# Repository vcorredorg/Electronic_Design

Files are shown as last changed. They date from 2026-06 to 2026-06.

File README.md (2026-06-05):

# Lock-in Amplifier
## Overview

This repository contains the development files, documentation, firmware, and interface resources for a digital lock-in amplifier based on the open-source OLIA architecture. The project implements a compact embedded instrumentation system capable of extracting amplitude, phase, and harmonic information from weak periodic signals using synchronous detection techniques.

A lock-in amplifier is especially useful when the signal of interest is buried in noise or when conventional amplitude measurements are not sufficient. By using a known reference signal, the system can isolate the component of the measured signal that is correlated with the reference frequency. This makes the instrument suitable for experimental electronics, sensors, optical measurements, signal characterization, and academic instrumentation projects.

The implementation is built around the Teensy 4.0 microcontroller and developed using Visual Studio Code, PlatformIO, and Zephyr. In addition to the embedded firmware, the project includes a basic graphical user interface for visualizing magnitude, phase, and harmonic components, as well as modifying user-configurable acquisition and processing parameters.

## Project Purpose

The main purpose of this project is to develop a low-cost, configurable, and educational digital lock-in amplifier that can be used as an alternative to conventional laboratory instrumentation in controlled experimental environments.

Many measurement systems require detecting very small periodic signals in the presence of broadband noise, DC offsets, interference, or unwanted spectral components. Direct measurement methods may fail when the signal-to-noise ratio is too low. This project addresses that problem by implementing digital synchronous demodulation, allowing the system to recover the amplitude and phase of a signal at a known reference frequency and at selected harmonic components.

The project also aims to document the complete engineering development process, including firmware structure, signal-processing logic, hardware documents, user-interface design, requirements, testing procedures, and system validation. Therefore, the repository is intended not only as a functional implementation but also as a technical reference for understanding how a microcontroller-based lock-in amplifier can be designed, programmed, tested, and documented.

## Main Features

* Embedded signal-processing system using the Teensy 4.0 development board.
* Synchronous detection for extracting signal magnitude and phase relative to a reference signal.
* Harmonic analysis for evaluating signal components at selected multiples of the reference frequency.
* Firmware developed with PlatformIO and Zephyr inside Visual Studio Code.
* Modular firmware organization for acquisition, processing, configuration, communication, and reporting tasks.
* Basic graphical user interface for:

  * Magnitude visualization.
  * Phase visualization.
  * Harmonic visualization.
  * User-defined configuration parameters.
* Project documentation organized for academic and engineering use.
* Adaptable architecture for future improvements such as calibration, advanced filtering, data logging, communication protocols, and extended visualization tools.

## Repository Structure

The repository is organized to separate hardware design files, technical documentation, embedded firmware, and the graphical user interface. The structure follows the general organization of the OLIA reference project, which separates firmware, GUI, board files, and documentation, while adapting it to this Teensy 4.0 + Zephyr + PlatformIO implementation.

```text
.
├── README.md
│
├── altium/
│   ├── files/
│   └── gerbers.zip
│
├── documents/
│   ├── application_note.pdf
│   └── power_tree/
|   └── block diagram
|   └──slides
|   └──technical_data.csv
│
├── firmware/
│       ├── CMakeLists.txt
│       └── src/
│           ├── main.c
│           ├── app/
│           │   ├── control.c
│           │   ├── control.h
│           │   ├── serial_protocol.c
│           │   └── serial_protocol.h
│           ├── dsp/
│           │   ├── lockin_core.c
│           │   └── lockin_core.h
│           └── hal/
│               ├── adc_backend.c
│               ├── adc_backend.h
│               ├── gpio_backend.c
│               ├── gpio_backend.h
│               ├── pwm_backend.c
│               ├── pwm_backend.h
│               ├── uart_backend.c
│               └── uart_backend.h
│
└── gui/
    ├── lockin_gui.py
    └── requirements.txt
```

Suggested directory purpose:

* `firmware/`: contains the embedded code for the Teensy 4.0, including acquisition, demodulation, harmonic calculation, configuration handling, and communication modules.
* `hardware/`: contains connection diagrams, schematics, wiring references, datasheets, and hardware-related notes.
* `documents/`: contains the formal project documentation, including requirements, architecture, state diagram and design explanations.
## Technologies Used

* **Teensy 4.0**
  Main embedded processing platform. The Teensy 4.0 is based on an ARM Cortex-M7 microcontroller running at 600 MHz, which provides enough computational capability for real-time digital signal processing, harmonic calculation, communication handling, and user-configuration tasks. Its floating-point support and high clock frequency make it suitable for implementing a compact digital lock-in amplifier.

* **PlatformIO**
  Embedded development environment used to manage project configuration, dependencies, compilation, board settings, and firmware upload.

* **Zephyr**
  Real-time operating system used to structure the embedded application into manageable tasks, improve modularity, and support a more organized firmware architecture.

* **Visual Studio Code**
  Main development environment used for firmware editing, project management, compilation, and debugging workflow.

* **C / C++**
  Primary programming language for the embedded firmware, signal-processing routines, hardware abstraction, and communication logic.

* **Graphical User Interface**
  Basic interface developed to display magnitude, phase, and harmonic information, and to allow user configuration of the system.

## Reference Project

This project is based on the open-source OLIA project:

* OLIA Repository: https://github.com/ajharvie/OLIA

OLIA is an open digital lock-in amplifier designed around the Teensy 4.0. This repository uses OLIA as a technical reference and adapts its concepts to the specific goals, implementation decisions, and documentation structure of this project.

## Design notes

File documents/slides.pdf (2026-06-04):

# PROYECTO - DISEÑO

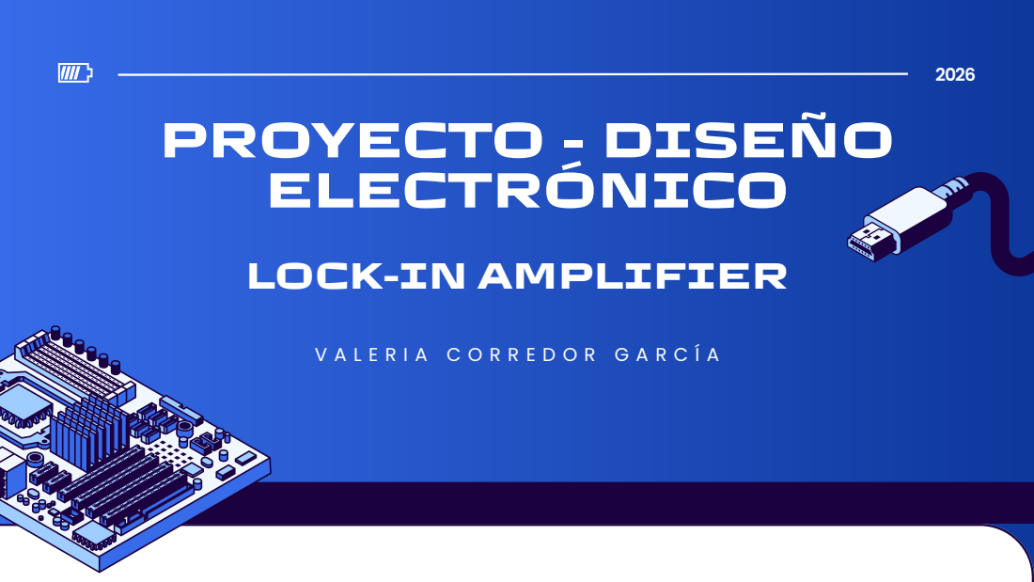
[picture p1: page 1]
ELECTRÓNICO

LOCK-IN AMPLIFIER

P

R

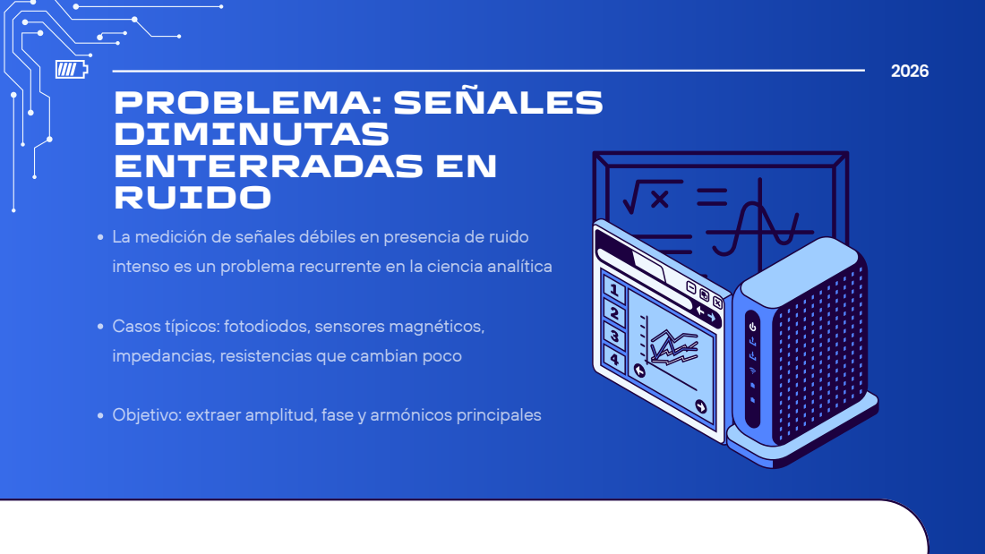
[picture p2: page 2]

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
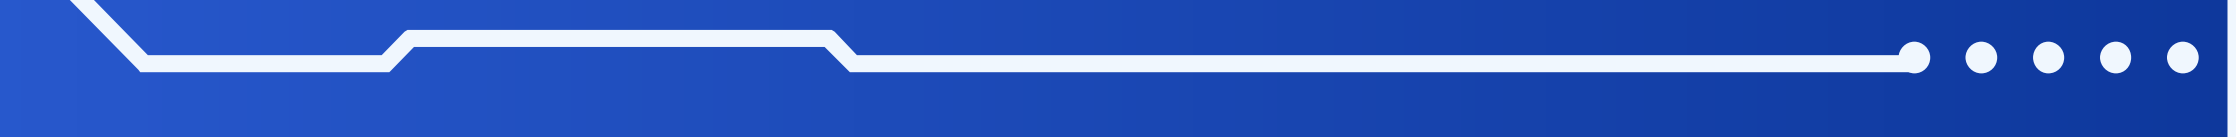
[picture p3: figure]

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
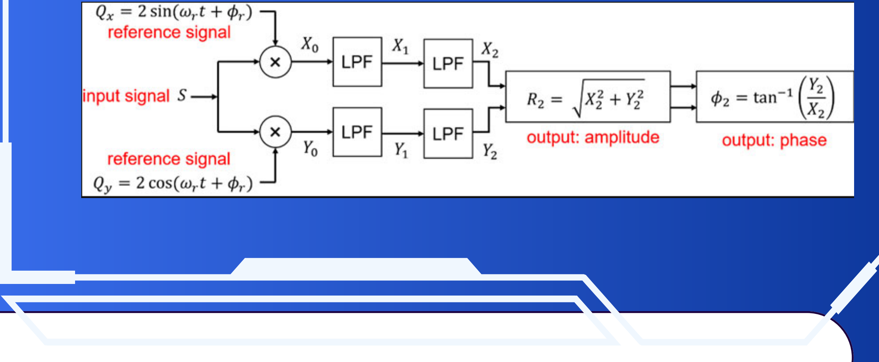
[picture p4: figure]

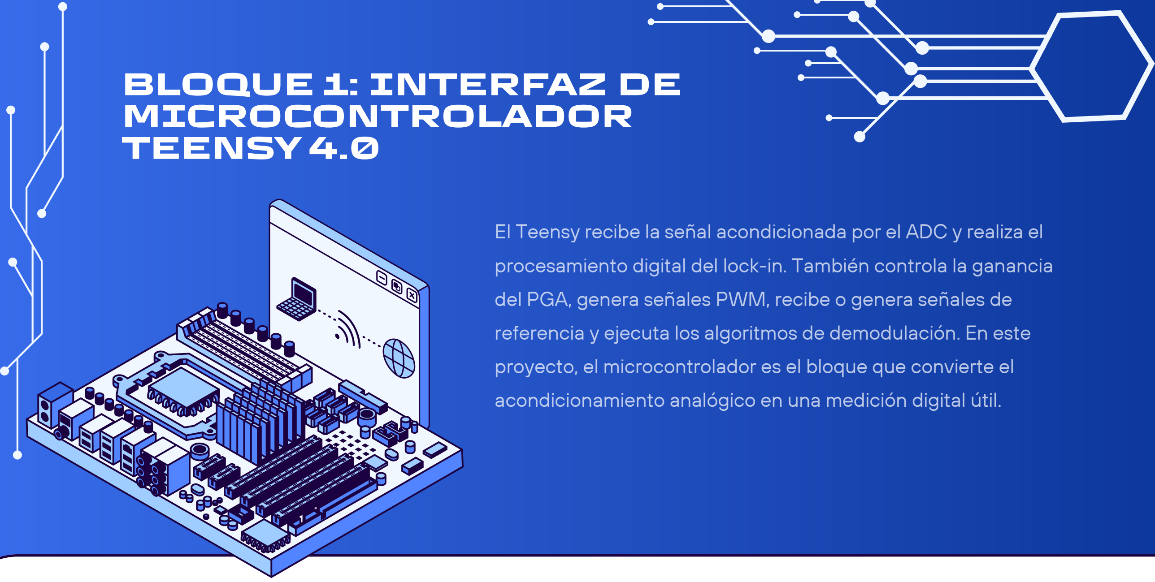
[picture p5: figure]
BLOQUE 1: INTERFAZ DE MICROCONTROLADOR TEENSY 4.0

El Teensy recibe la señal acondicionada por el ADC y realiza el procesamiento digital del lock-in. También controla la ganancia del PGA, genera señales PWM, recibe o genera señales de referencia y ejecuta los algoritmos de demodulación. En este proyecto, el microcontrolador es el bloque que convierte el acondicionamiento analógico en una medición digital útil.

## BLOQUE 2: RIEL DE VOLTAJE NEGATIVO

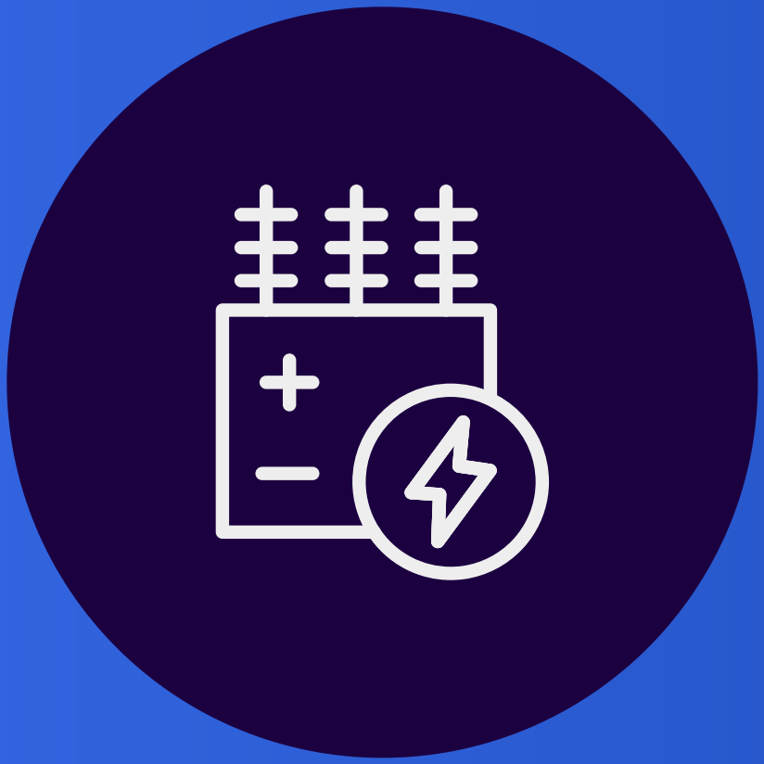
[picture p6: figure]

Este bloque crea un riel de tensión negativa a partir de la alimentación positiva disponible. La tensión negativa permite que los amplificadores analógicos trabajen con señales bipolares. Esto es importante porque la señal de entrada del lock-in puede estar centrada alrededor de cero y no solo en valores positivos.

B

L

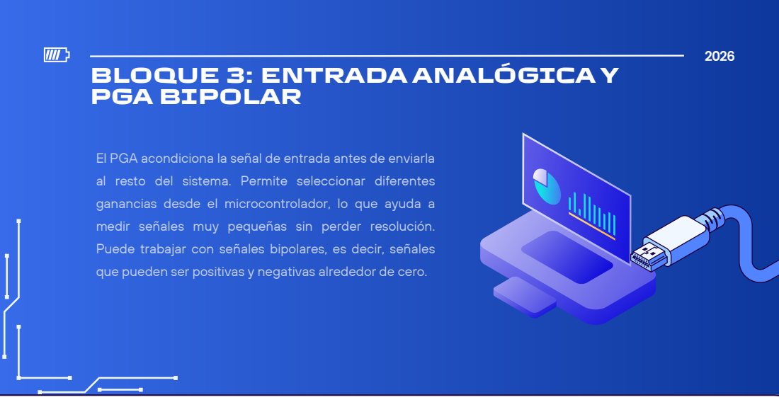
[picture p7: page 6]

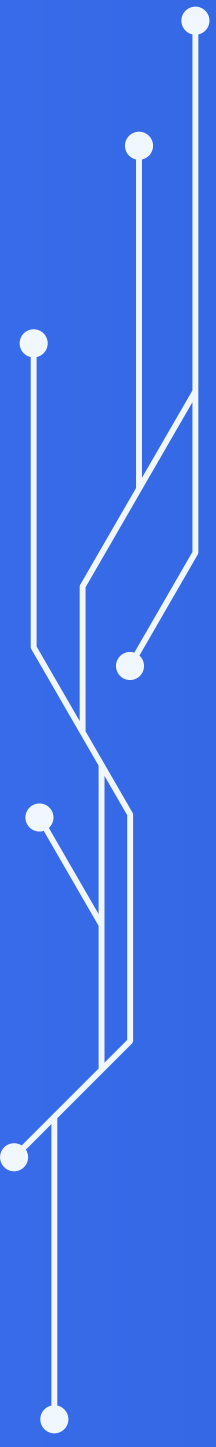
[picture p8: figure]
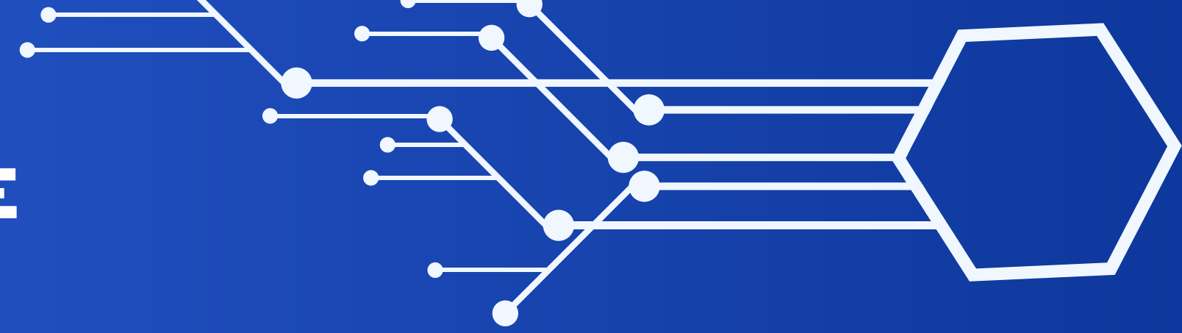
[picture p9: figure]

## BLOQUE 4: ETAPA DE OFFSET

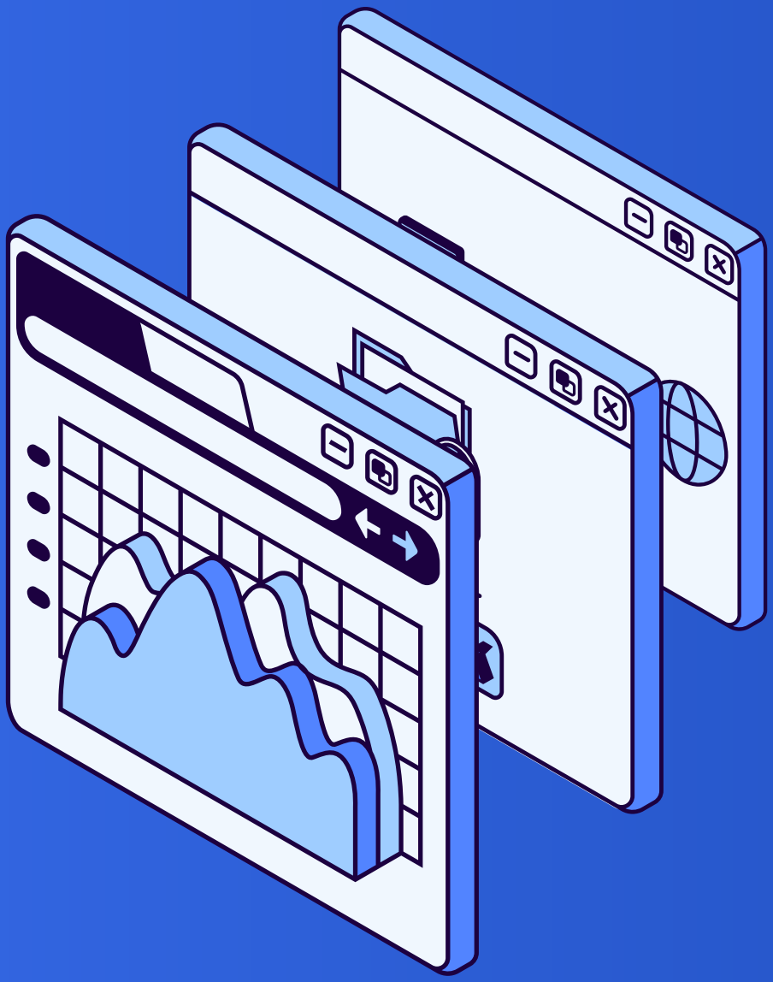
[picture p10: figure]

Después de acondicionar la señal se adaptarla a la entrada del ADC. Como el ADC del microcontrolador solo trabaja con tensiones positivas, este bloque desplaza la señal hacia un rango seguro de lectura. En otras palabras, convierte una señal centrada en cero en una señal centrada alrededor de un nivel positivo, sin perder la información de variación de la señal original.

## BLOQUE 5: FILTRO ANTI ALIAS

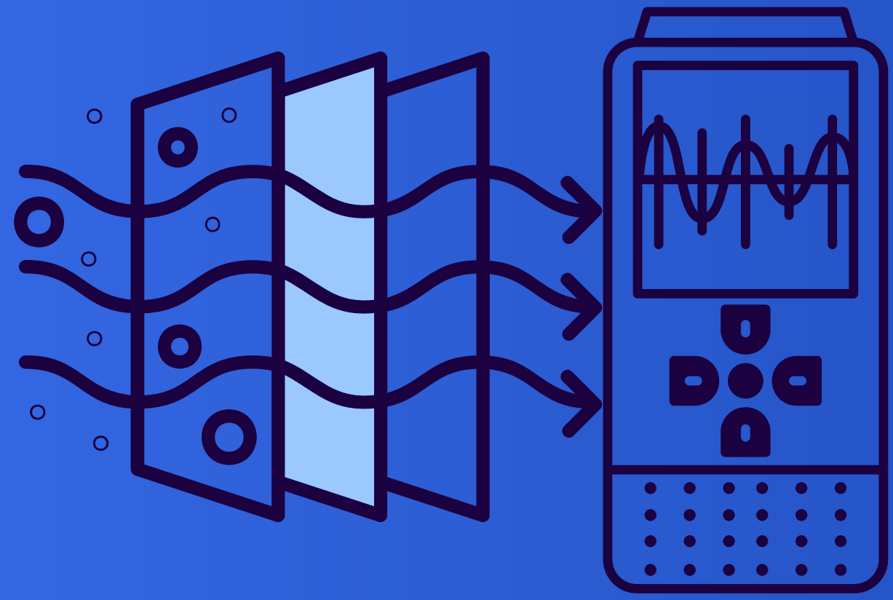
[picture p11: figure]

El filtro anti-aliasing elimina componentes de alta frecuencia que podrían producir errores durante el muestreo. Su objetivo es que el ADC reciba una señal más limpia y que las frecuencias no deseadas no se mezclen con la señal útil. Esto es importante en un lock-in amplifier porque la medición depende de extraer una componente muy específica de frecuencia.

## BLOQUE 6: SALIDA ANALÓGICA PWM FILTRADA

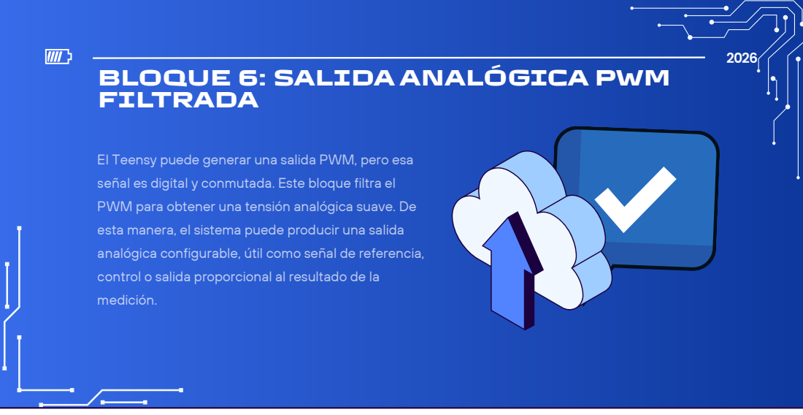
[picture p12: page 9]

El Teensy puede generar una salida PWM, pero esa
señal es digital y conmutada. Este bloque filtra el
PWM para obtener una tensión analógica suave. De
esta manera, el sistema puede producir una salida
analógica configurable, útil como señal de referencia,
control o salida proporcional al resultado de la
medición.

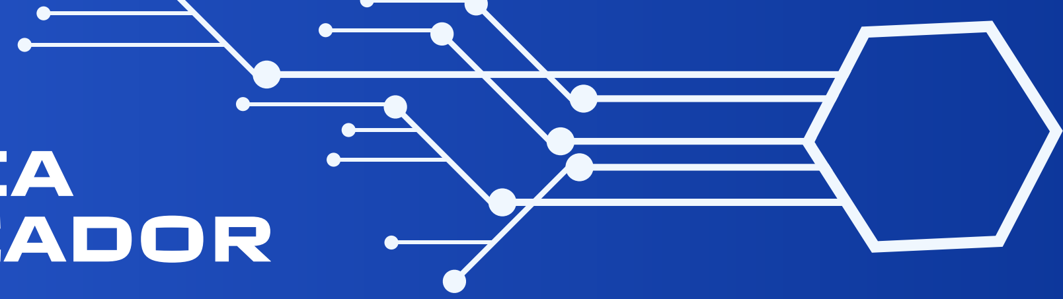
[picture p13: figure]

## BLOQUE 7: REFERENCIA EXTERNA Y MULTIPLICADOR DE RELOJ X64

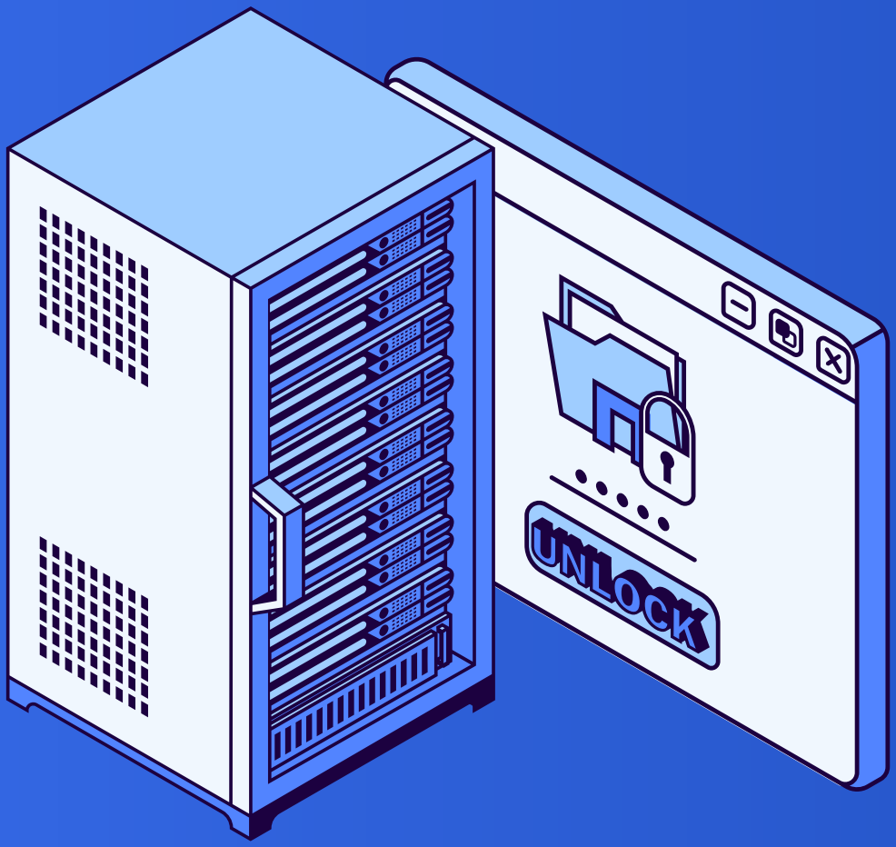
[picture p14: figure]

Este bloque toma una referencia externa y usa un PLL para generar un reloj sincronizado de mayor frecuencia. La multiplicación por 64 permite obtener una referencia temporal más fina para el procesamiento digital. En un lock-in amplifier, la sincronización con la referencia es esencial, porque la señal medida se compara con esa referencia para extraer amplitud y fase..

# MUCHAS

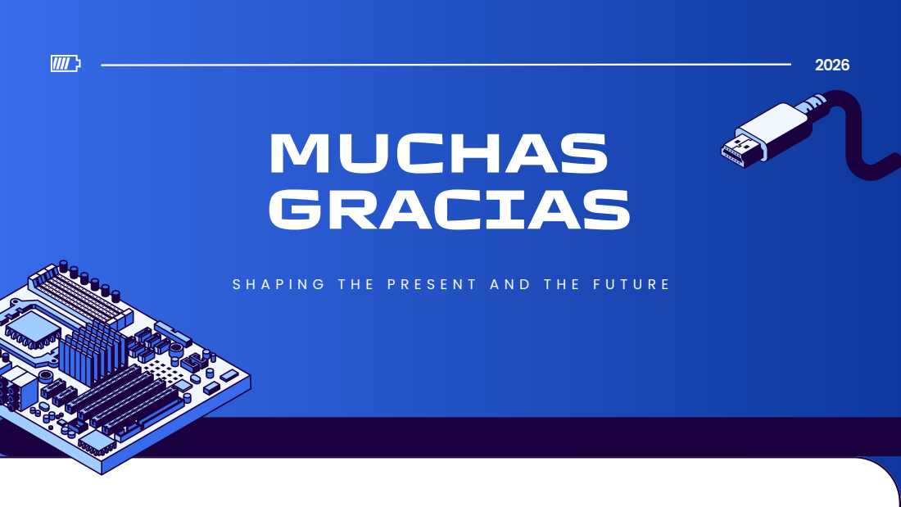
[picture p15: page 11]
GRACIAS

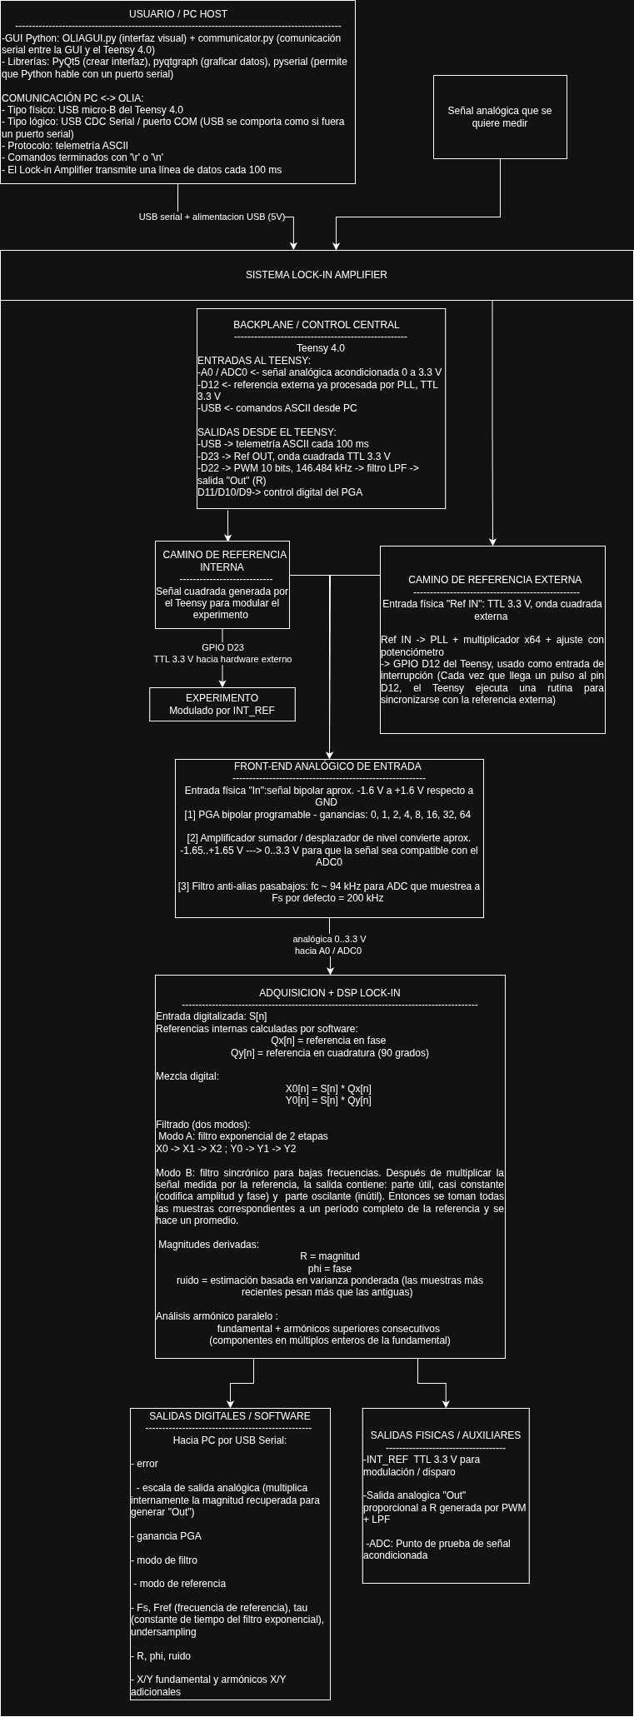
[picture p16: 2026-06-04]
documents/block diagram.png

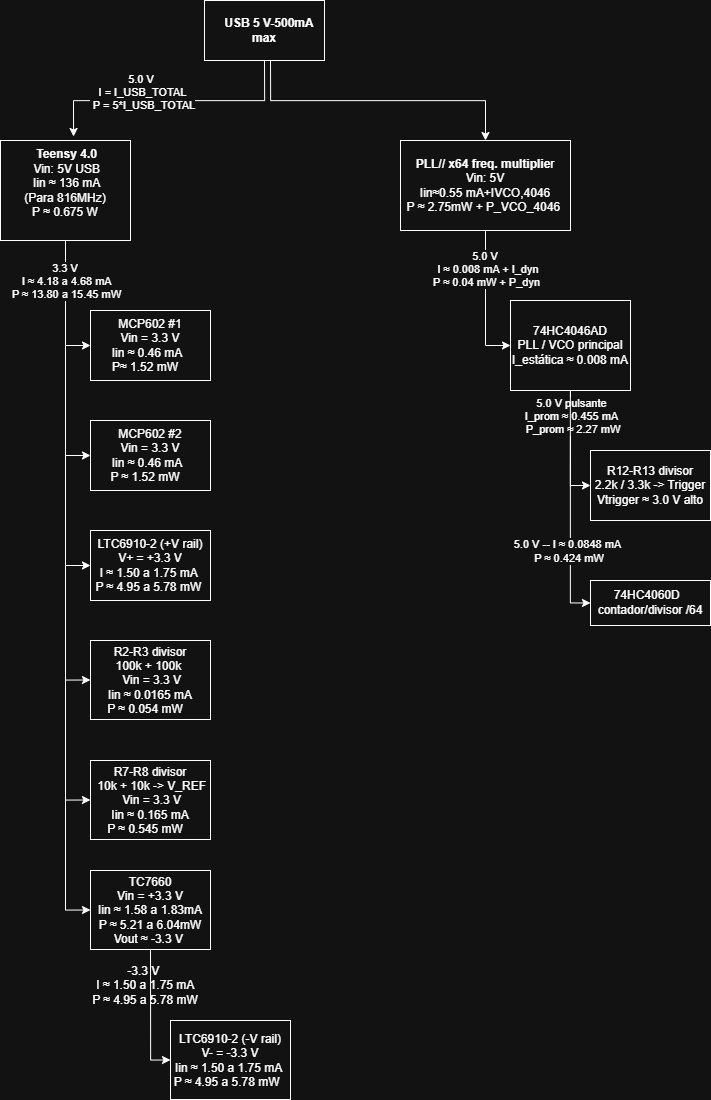
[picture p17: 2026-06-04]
documents/power_tree/power_tree.png

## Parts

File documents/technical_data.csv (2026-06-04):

Tabla 1 — Frecuencias, tasas y tiempos importantes
Parámetro | Valor | Parte del sistema | Importancia para el proyecto | Fuente / referencia
Frecuencia de CPU de Teensy 4.0 | 600 MHz | Microcontrolador Teensy 4.0 | Frecuencia principal de procesamiento; permite adquisición, demodulación digital, cálculo de magnitud/fase y armónicos en tiempo real. | https://www.pjrc.com/store/teensy40.html
Cristal principal de Teensy 4.0 | 24 MHz | Reloj base del microcontrolador | Referencia física usada por la Teensy para generar el reloj del sistema mediante PLL interno. | https://www.pjrc.com/store/teensy40.html
SysTick | 1 kHz equivalente | Temporización del sistema | Genera una base temporal de 1 ms para tareas periódicas no críticas, monitoreo o temporización general. | https://www.pjrc.com/store/teensy40.html
Velocidad USB device | 480 Mbit/s | Comunicación Teensy-PC | Enlace principal para enviar datos procesados a la interfaz gráfica. | https://www.pjrc.com/store/teensy40.html
Rango de frecuencia lock-in Amplifier | 10 Hz – 50 kHz | Referencia del proyecto base | Rango funcional declarado para lock-in amplifier digital; sirve como referencia de desempeño. | https://github.com/OpenLockIn/OLIA
Frecuencia de modulación interna | 1 Hz – 50 kHz | Modo de referencia interna | La GUI permite modificar la frecuencia de modulación interna dentro de este rango. | https://doi.org/10.3389/fsens.2023.1102176
Tasa de digitalización por defecto | 200 kHz | ADC / adquisición | Define el límite de Nyquist, la carga computacional y el número de armónicos que pueden calcularse. | https://doi.org/10.3389/fsens.2023.1102176
Periodo de muestreo asociado | 5 µs | ADC / DSP | Corresponde a Ts = 1 / 200000; es la ventana temporal disponible por muestra. | https://doi.org/10.3389/fsens.2023.1102176
Frecuencia de Nyquist del ADC | 100 kHz | Adquisición digital | Mitad de 200 kHz; señales por encima pueden producir aliasing si no se filtran antes del ADC. | Cálculo directo a partir de Fs = 200 kHz
Filtro anti-aliasing analógico | 94 kHz | Acondicionamiento analógico | Filtro pasa-bajas previo al ADC, ubicado por debajo de Nyquist para atenuar componentes superiores. | https://doi.org/10.3389/fsens.2023.1102176
Multiplicador de referencia externa | ×64 | PLL externo / hardware de referencia | Genera 64 ciclos de reloj por cada ciclo TTL de referencia externa. | https://doi.org/10.3389/fsens.2023.1102176 ; https://raw.githubusercontent.com/vcorredorg/Electronic_Design/main/documents/power_tree/power_tree.png
Divisor de referencia | /64 | 74HC4060D / referencia | Bloque usado para dividir la señal generada o reconstruir relaciones de referencia. | https://raw.githubusercontent.com/vcorredorg/Electronic_Design/main/documents/power_tree/power_tree.png
Rango de referencia externa del PLL OLIA | 130 Hz – 6 kHz | Modo de referencia externa | Rango de entrada TTL externa para los valores de diseño indicados. | https://doi.org/10.3389/fsens.2023.1102176
Límite de cambio de estrategia de muestreo externa | 1562.5 Hz | Referencia externa | Por debajo de este valor se toman muestras en flanco de subida y bajada, logrando 128 muestras por ciclo TTL. | https://doi.org/10.3389/fsens.2023.1102176
Segundo umbral de referencia externa | 3125 Hz | Referencia externa | Entre 1562.5 Hz y 3125 Hz se toman 64 muestras por ciclo TTL; por encima se submuestrea. | https://doi.org/10.3389/fsens.2023.1102176
Muestras por ciclo en referencia externa baja | 128 muestras/ciclo | ADC sincronizado | Aplica para f_TTL < 1562.5 Hz; mejora la resolución de fase por ciclo. | https://doi.org/10.3389/fsens.2023.1102176
Muestras por ciclo en referencia externa media | 64 muestras/ciclo | ADC sincronizado | Aplica entre 1562.5 Hz y 3125 Hz. | https://doi.org/10.3389/fsens.2023.1102176
Muestras por ciclo en referencia externa alta | 64/N muestras/ciclo | ADC sincronizado | Para f_TTL > 3125 Hz, con N = 2, 4, 8, 16, para mantener Fs bajo 200 kHz. | https://doi.org/10.3389/fsens.2023.1102176
Actualización de datos por USB/GUI | 0.1 s = 10 Hz | Interfaz gráfica | Frecuencia de envío/actualización de valores de magnitud, fase, componentes X/Y y ruido hacia la GUI. | https://doi.org/10.3389/fsens.2023.1102176
Constante de tiempo configurable | 0.01 s – 10 s | Filtro digital | Controla el compromiso entre rechazo de ruido y velocidad de respuesta. | https://doi.org/10.3389/fsens.2023.1102176
Tiempo de estabilización recomendado | ≈ 10τ | Medición lock-in | Después de cambiar una configuración, se recomienda esperar aproximadamente diez constantes de tiempo. | https://doi.org/10.3389/fsens.2023.1102176
Límite típico para filtrado síncrono | < 100 Hz | DSP / filtrado | Recomendado principalmente para señales limpias de baja frecuencia. | https://doi.org/10.3389/fsens.2023.1102176
PWM en Teensy 4.0 | 31 pines PWM, 19 grupos de frecuencia | Salidas digitales | Puede servir para generar señales de referencia, modulación o control; la frecuencia depende de configuración por software. | https://www.pjrc.com/store/teensy40.html
Tabla 2 — Datos técnicos importantes del proyecto
Dato | Valor / descripción | Uso en la exposición | Fuente / referencia
Entrada analógica OLIA | −1.6 V a +1.6 V aprox. | Rango bipolar de entrada del proyecto de referencia. | https://github.com/OpenLockIn/OLIA
Rango de entrada acondicionado al ADC | 0 V – 3.3 V | La señal bipolar se desplaza/acondiciona para ser compatible con el ADC de la Teensy. | https://doi.org/10.3389/fsens.2023.1102176
Resolución ADC usada en OLIA | 12 bits | Las muestras del ADC se obtienen como enteros de 12 bits y luego se procesan digitalmente. | https://doi.org/10.3389/fsens.2023.1102176
Precisión de cálculo | 64-bit double | Los cálculos digitales usan doble precisión aprovechando la FPU de la Teensy 4.0. | https://doi.org/10.3389/fsens.2023.1102176
Ganancia de entrada OLIA | 0, 1, 2, 4, 8, 16, 32, 64 | Permite adaptar señales pequeñas o grandes al rango útil del ADC. | https://doi.org/10.3389/fsens.2023.1102176
Armónicos por defecto en OLIA | Fundamental + armónicos 2, 3 y 4 | A 200 kHz hay margen computacional para analizar tres armónicos adicionales además de la fundamental. | https://doi.org/10.3389/fsens.2023.1102176
Armónicos si se reduce muestreo | Hasta 7 armónicos superiores a 100 kHz | Al bajar la frecuencia de muestreo aumenta el tiempo disponible por muestra, permitiendo calcular más armónicos. | https://doi.org/10.3389/fsens.2023.1102176
Alimentación principal en el power tree | USB 5 V, 500 mA máx. | Fuente general del sistema según el diagrama de potencia del repositorio. | https://raw.githubusercontent.com/vcorredorg/Electronic_Design/main/documents/power_tree/power_tree.png
Consumo estimado Teensy en el power tree | ≈ 136 mA, ≈ 0.675 W | Dato útil para justificar el presupuesto de potencia de la placa. | https://raw.githubusercontent.com/vcorredorg/Electronic_Design/main/documents/power_tree/power_tree.png
Interfaz de usuario | GUI para visualización y configuración | Permite observar magnitud, fase, armónicos y modificar parámetros de usuario. | https://github.com/vcorredorg/Electronic_Design/tree/main

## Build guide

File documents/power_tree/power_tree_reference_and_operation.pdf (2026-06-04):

REFERENCIAS DEL POWER TREE

- Teensy 4.0(MCU): https://www.pjrc.com/store/teensy40.html
A 600MHz consume 100mA, para 816MHz (aproximación), muestras de 12 bits

Iin =

816MHz ∗ 100mA
600MHz = 136mA
- TC7660 (genera riel de -3.3 V para operación bipolar del PGA):
-Datasheet: https://ww1.microchip.com/downloads/en/DeviceDoc/21465C.pdf -Conmuta a 10kHz, bajo consumo de corriente, requiere solo dos capacitores externos;

Pout ≈ 3.3 ⋅ (1.50 a 1.75) mA ≈ 4.95 a 5.78 mW

El datasheet del TC7660 dice que tiene una eficiencia de potencia típica de 98%, entonces:

Pin ≈

Pout
η

y como la entrada es de aproximadamente +3.3 V:

Iin ≈

Pout
η ⋅ Vin

Como en este caso Vin ≈∣ Vout ∣≈ 3.3 V, eso se simplifica mucho:

Iin ≈

Iout
η

Si se toma η ≈ 0.98, entonces:

Iin ≈

1.50 a 1.75
0.98 ≈ 1.53 a 1.79 mA

y después se suma el consumo propio del chip: Iin_total ≈ 1.53 a 1.79 + 0.08 ≈ 1.61 a 1.87 mA

- LTC6910-2(PGA-ajusta la ganancia de entrada):
-Datasheet: https://www.analog.com/media/en/technical-documentation/datasheets/6910fb.pdf (https://www.analog.com/media/en/technical-documentation/data-sheets/6910fb.pdf)
-Inversor, reduce componentes externos, ganancia-ancho de banda típico de aproximadamente 13 MHz en ganancia 64 bajo ciertas condiciones.

El datasheet menciona “: Vs = ±5V: 3mA o 3.5mA”, entonces para aproximar:

I+ ≈ I− ≈

Itotal
2
Por lo tanto:

I−3.3V ≈

3.0 mA
2

= 1.50 mA

I−3.3V ≈

3.5 mA
2

= 1.75 mA

Ganancia | Rango de entrada aproximado antes del ADC
0 | Entrada apagada
1 | ±1.65 V
2 | ±825 mV
4 | ±412 mV
8 | ±206 mV
16 | ±103 mV
32 | ±51.6 mV
64 | ±25.8 mV
- MCP602 (filtro):
- Datasheet:https://ww1.microchip.com/downloads/aemDocuments/documents/APID/ProductDocuments/DataSheets/20001685E.pdf
- Amplificador operacional CMOS doble (dos op-amps independientes), rail to rail.
- Se muestrea por defecto a 200 kS/s, por lo que la frecuencia de Nyquist es:
fN = 100 kHz

Por eso usa un filtro antialiasing de 94 kHz, ligeramente por debajo de Nyquist.
- El MCP602 tiene un producto ganancia-ancho de banda típico de 2.8 MHz y es estable en ganancia unitaria.
Iin (por amplificador):230uA; como es Dual
230uA ∗ 2 = 0.46mA por cℎip ETAPA DE OFFSET
- R2 y R7: divisor para crear 1.65 V: 10k e I= 165uA Es suficientemente baja para no gastar mucha potencia, pero suficientemente alta para que el nodo de 1.65 V no sea demasiado frágil.

- R3 y R5: promedian señal + offset: Como la entrada del op-amp idealmente no consume corriente, ese nodo queda aproximadamente como el promedio de ambas tensiones
- R4 y R6: amplificador no inversor con ganancia 2

ETAPA DE FILTRO ANTI-ALIASING: filtro pasa-bajas activo tipo Sallen-Key de ganancia unitaria, con frecuencia de corte en 94kHz

Fc =

1
2 ∗ π√R1 ∗ R2 ∗ C1 ∗ C2
-Filtro PWM:

Fc =

1
2 ∗ π ∗ R ∗ C

= 1. 6 Hz

La PWM de OLIA trabaja alrededor de 146 kHz, eso significa que la componente rápida de PWM queda fuertemente atenuada. El filtro deja pasar el valor promedio lento, pero elimina casi por completo el rizado rápido.

- 74HC4046AD (PLL-sincroniza fase y genera la frecuencia multiplicada): sistema de realimentación. Su objetivo no es simplemente generar una frecuencia, sino hacer que un oscilador local siga la fase de una señal de referencia.
- Datasheet:https://assets.nexperia.com/documents/data-sheet/74HC_HCT4046A.pdf Se divide la corriente en dos partes:

I4046 ≈ Iestaˊ tica + Idinaˊmica

Iestaˊ tica = 8uA
Cálculo de Iprom(corriente promedio del divisor resistivo que puse a la salida del VCO hacia el Teensy):
por las dos resistencias en serie es (una de 2.2 kΩ y una de 3.3 kΩ):

Ialto =

V
R12 + R13

=

5
2.2k + 3.3k

=

5
5.5k

= 0.909 mA

el divisor consume aproximadamente:
Ialto ≈ 0.909 mA
Pero el datasheet del 4046 dice que, cuando el nivel DC de VCO_IN se mantiene constante, la señal VCO_OUT tiene un duty cycle de 50 % con una desviación máxima esperada de 1 %. Eso quiere decir que, idealmente, la señal pasa la mitad del tiempo en alto y la mitad del tiempo en bajo. Cuando está en bajo, la corriente del divisor es prácticamente:

Ibajo ≈ 0

Entonces la corriente promedio del divisor es:

Iprom = D ⋅ Ialto

con D = 0.5. Por tanto:
Iprom = 0.5 ⋅ 0.909 mA = 0.4545 mA ≈ 0.455 mA
- la hoja de datos indica que el VCO necesita un capacitor externo entre C1A y C1B, y una resistencia externa hacia tierra para definir el rango de frecuencia

Determinar el rango de frecuencia del VCO
- C4= 820pF: C14 es el capacitor de temporización del VCO. Internamente, el 4046 carga y descarga ese capacitor. La frecuencia aumenta cuando el capacitor se carga y descarga más rápido. Al aumentar C14, baja la frecuencia máxima. Al reducir C14, sube la frecuencia máxima, pero el circuito se vuelve más sensible a capacitancias parásitas.
- P1=200K: Ajustar P1 cambia el rango de frecuencia libre del VCO. Esto es importante porque un PLL no puede bloquear cualquier frecuencia arbitraria: el VCO debe ser capaz de generar aproximadamente:

fVCO ≈ 64fEXTREF

Si el VCO libre está demasiado lejos, el lazo puede no capturar la referencia. P1 permite calibrar el rango. En un lock-in, esto es útil porque la referencia externa puede cambiar, y el reloj interno debe poder seguirla. -----------------------------------------------------------------------------------------------------------
- PC2OUT: Este es el comparador de fase 2, que en realidad es un detector de fase. PC2 no solo sabe si una señal está adelantada o atrasada; también sabe si una frecuencia es mayor o menor que la otra

Filtro R12-C16-R14: Este filtro convierte los pulsos de corrección del comparador de fase en una tensión relativamente suave para el VCO
- R12 = 220 kΩ limita la corriente de carga/descarga desde PC2OUT hacia el nodo PLLCTRL. Hace que el PLL no reaccione violentamente a cada pulso.
-C16 = 1.5 µF almacena la tensión de control. Es la “memoria analógica” del PLL. -.R14 = 4.7 kΩ introduce un cero en la respuesta del filtro. Esto ayuda a la estabilidad y evita que el lazo sea excesivamente integrador y oscilatorio.
- 74HC4060D (cuenta y divide la frecuencia): https://assets.nexperia.com/documents/data-sheet/74HC_HCT4060.pdf Retomando:

I4046 ≈ Iestaˊ tica + Idinaˊmica
De acuerdo con el datasheet:

Iestaˊ tica = 8uA

Se toma el peor caso del lock-in amplifier en referencia externa: el multiplicador genera 64 ciclos por cada ciclo de referencia y admite hasta 6 kHz (de ref externa).
f ≈ 64 × 6 kHz = 384 kHz
La parte dinámica se calcula con la fórmula que da el propio datasheet usando la capacitancia de disipación CPD:

PD = CPD VCC

2 fi N + ∑(CL VCC

2 fo)

y para el 74HC4060 a 5 V el datasheet da CPD = 40 pF con N = 1 (número de entradas del chip que están cambiando de estado - RS).
Entonces:

Pdinamica ≈ CPD V

2 f
Al sustituir:

Pdinamica ≈ 40 × 5

2 × 0.384

Pdinamica ≈ 40 × 25 × 0.384

Pdinamica ≈ 0.384 mW
Para la corriente dinámica:

Idinamica =

P
V

=

0.384 mW
5 V

= 0.0768 mA

Ahora se suma:
Itotal ≈ 0.008 + 0.0768 = 0.0848 mA

y luego la potencia total: P = V ⋅ I = 5 × 0.0848 mA = 0.424 mW

- Divisores resistivos: Las corrientes de esos bloques se calculan con:

I =

V

Rtotal

R11 = 2.2 kΩ y R13 = 3.3 kΩ: La salida VCLOCK del 4046 está alimentada a 5 V, así que su nivel alto será cercano a 5 V. Pero si TRIGGER va hacia una Teensy 4.0, no conviene aplicar 5 V directamente: PJRC indica que los pines digitales de Teensy 4.0 aceptan señales de 0 a 3.3 V y no son tolerantes a 5 V

El divisor hace:

VTRIGGER = VVCLOCK

R13
R11 + R13

Con tus valores:

VTRIGGER = 5V

3.3k
2.2k + 3.3k
VTRIGGER ≈ 3.0V

RESUMEN DE FUNCIONAMIENTO PLL:

1. Entra señal de referencia externa
2. Se compara señal externa con la PLLDIV64 por medio de PC2OUT (entrega pulsos de corrección)
3. Filtro de lazo: convierte los pulsos digitales de PC2OUT en una tensión analógica llamada PLLCTRL
4. Realimentación con PLLCTRL
5. Se genera VCOCLK
6. Luego VCLOCK se divide en el 4060
7. La señal PLLDIV64 vuelve al pin 3 del 4046

-La idea fundamental es esta:

f(t) =

1
2π

dφ(t)
dt

La frecuencia es la derivada temporal de la fase. Por eso, si dos señales tienen una diferencia de fase constante, entonces sus frecuencias son iguales. Un PLL usa este principio:
1. Compara la fase de una señal externa con la fase de una señal generada localmente.

Compara:

fEXTREF contra

fVCLOCK
64 = fPLLDIV64

Por eso, cuando el PLL está bloqueado:

fEXTREF =

fVCLOCK
64

y por tanto:

fVCLOCK = 64fEXTREF

fPLLDIV64 = fEXTRF y además intenta que queden con una diferencia de fase estable. Idealmente:

φPLLDIV64 ≈ φEXTRF

-Si PLLDIV64 va más lenta que la referencia, el PLL sube el voltaje PLLCTRL, aumentando la frecuencia del VCO. Si PLLDIV64 va más rápida, baja PLLCTRL, reduciendo la frecuencia del VCO. Cuando ambas tienen la misma frecuencia y una fase estable, se dice que el PLL está locked o enganchado.

2. el 4046 genera VCLOCK, el 4060 divide VCLOCK entre 64, y el 4046 ajusta su VCO hasta que la señal dividida coincida con la referencia externa.

-VCLOCK entra al 4060.

-El 4060 cuenta pulsos.

-Una salida intermedia se llama PLLDIV64.

-PLLDIV64 vuelve al pin COMPIN del 4046.

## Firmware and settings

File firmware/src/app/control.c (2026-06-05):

#include "zephyr_compat.h"
#include "control.h"
#include "serial_protocol.h"
#include "lockin_core.h"
#include "adc_backend.h"
#include "gpio_backend.h"
#include "pwm_backend.h"
#include "uart_backend.h"

#include <errno.h>
#include <stddef.h>
#include <stdint.h>
#include <string.h>

#define SAMPLE_STACK_SIZE   4096
#define REPORT_STACK_SIZE   4096
#define SERIAL_STACK_SIZE   2048
#define CONTROL_STACK_SIZE  2048

#define SAMPLE_PRIORITY     0
#define CONTROL_PRIORITY    2
#define SERIAL_PRIORITY     3
#define REPORT_PRIORITY     4

K_THREAD_STACK_DEFINE(sample_stack, SAMPLE_STACK_SIZE);
K_THREAD_STACK_DEFINE(report_stack, REPORT_STACK_SIZE);
K_THREAD_STACK_DEFINE(serial_stack, SERIAL_STACK_SIZE);
K_THREAD_STACK_DEFINE(control_stack, CONTROL_STACK_SIZE);

static struct k_thread sample_thread;
static struct k_thread report_thread;
static struct k_thread serial_thread;
static struct k_thread control_thread;

static struct k_sem sample_sem;
static struct k_sem report_sem;
static struct k_sem control_sem;

static struct k_timer sample_timer;
static struct k_timer report_timer;
static struct k_timer external_gate_timer;

static atomic_t external_measure_done;
static atomic_t external_measure_active;
static atomic_t started;

static void start_internal_sampling_from_config(void)
{
    lockin_config_t cfg;
    lockin_core_get_config(&cfg);
    uint32_t dt = cfg.sample_dt_us;
    if (dt < 1u) {
        dt = 1u;
    }
    k_timer_start(&sample_timer, K_USEC(dt), K_USEC(dt));
}

static void sample_timer_handler(struct k_timer *timer)
{
    ARG_UNUSED(timer);
    k_sem_give(&sample_sem);
}

static void report_timer_handler(struct k_timer *timer)
{
    ARG_UNUSED(timer);
    k_sem_give(&report_sem);
}

static void external_gate_timer_handler(struct k_timer *timer)
{
    ARG_UNUSED(timer);
    atomic_set(&external_measure_done, 1);
    atomic_set(&external_measure_active, 0);
    k_sem_give(&control_sem);
}

static void external_sample_callback(void)
{
    if (!atomic_get(&external_measure_active)) {
        k_sem_give(&sample_sem);
    }
}

static void sample_entry(void *a, void *b, void *c)
{
    ARG_UNUSED(a);
    ARG_UNUSED(b);
    ARG_UNUSED(c);

    while (1) {
        k_sem_take(&sample_sem, K_FOREVER);
        uint16_t sample = 0;
        if (adc_backend_read(&sample) == 0) {
            lockin_core_process_sample(sample, lockin_now_us32());

            gpio_backend_set_reference(lockin_core_reference_high());
        }
    }
}

static void report_entry(void *a, void *b, void *c)
{
    ARG_UNUSED(a);
    ARG_UNUSED(b);
    ARG_UNUSED(c);

    char line[384];
    while (1) {
        k_sem_take(&report_sem, K_FOREVER);
        lockin_snapshot_t snapshot;
        lockin_core_snapshot(&snapshot);
        int n = serial_protocol_format_report(&snapshot, line, sizeof(line));
        if (n > 0) {
            uart_backend_write(line, (size_t)n);
        }
        uint16_t code = lockin_core_pwm_code_from_snapshot(&snapshot, 1023u);
        pwm_backend_write_code(code, 1023u);
    }
}

static void serial_entry(void *a, void *b, void *c)
{
    ARG_UNUSED(a);
    ARG_UNUSED(b);
    ARG_UNUSED(c);

    char line[80];
    size_t pos = 0;

    while (1) {
        uint8_t ch = 0;
        if (uart_backend_get_char(&ch) != 0) {
            continue;
        }

        if (ch == '\r' || ch == '\n') {
            if (pos > 0u) {
                line[pos] = '\0';
                serial_protocol_handle_line(line);
                pos = 0u;
            }
            continue;
        }

        if (pos < (sizeof(line) - 1u)) {
            line[pos++] = (char)ch;
        } else {
            pos = 0u;
        }
    }
}

static void apply_external_measurement_result(void)
{
    uint32_t edges = gpio_backend_get_and_clear_edge_count();
    float trigger_hz = (float)edges / 10.0f;

    uint32_t undersampling = 1u;
    uint32_t oversampling = 1u;
    uint32_t samples_per_period = LOCKIN_REFERENCE_MULTIPLIER;
    bool both_edges = false;

    if (trigger_hz <= 100000.0f) {
        undersampling = 1u;
        oversampling = 2u;
        samples_per_period = LOCKIN_REFERENCE_MULTIPLIER * 2u;
        both_edges = true;
    } else if (trigger_hz <= 200000.0f) {
        undersampling = 1u;
        oversampling = 1u;
        samples_per_period = LOCKIN_REFERENCE_MULTIPLIER;
    } else if (trigger_hz <= 400000.0f) {
        undersampling = 2u;
        oversampling = 1u;
        samples_per_period = LOCKIN_REFERENCE_MULTIPLIER / 2u;
    } else if (trigger_hz <= 800000.0f) {
        undersampling = 4u;
        oversampling = 1u;
        samples_per_period = LOCKIN_REFERENCE_MULTIPLIER / 4u;
    } else {
        undersampling = 8u;
        oversampling = 1u;
        samples_per_period = LOCKIN_REFERENCE_MULTIPLIER / 8u;
    }

    lockin_core_set_external_timing(trigger_hz, undersampling, oversampling, samples_per_period);
    gpio_backend_enable_external_irq(both_edges);
}

static void control_entry(void *a, void *b, void *c)
{
    ARG_UNUSED(a);
    ARG_UNUSED(b);
    ARG_UNUSED(c);

    while (1) {
        k_sem_take(&control_sem, K_FOREVER);
        if (atomic_cas(&external_measure_done, 1, 0)) {
            apply_external_measurement_result();
        }
    }
}

int control_init(void)
{
    k_sem_init(&sample_sem, 0, 1);
    k_sem_init(&report_sem, 0, 1);
    k_sem_init(&control_sem, 0, 1);

    k_timer_init(&sample_timer, sample_timer_handler, NULL);
    k_timer_init(&report_timer, report_timer_handler, NULL);
    k_timer_init(&external_gate_timer, external_gate_timer_handler, NULL);

    lockin_core_init();

    int ret = adc_backend_init();
    if (ret != 0) {
        printk("adc init failed: %d\n", ret);
    }

    ret = gpio_backend_init();
    if (ret != 0) {
        printk("gpio init failed: %d\n", ret);
    }

    gpio_backend_set_external_sample_callback(external_sample_callback);
    gpio_backend_set_gain_bits(LOCKIN_DEFAULT_GAIN);

    ret = pwm_backend_init();
    if (ret != 0) {
        printk("pwm init failed: %d\n", ret);
    }

    ret = uart_backend_init();
    if (ret != 0) {
        printk("uart init failed: %d\n", ret);
    }

    return 0;
}
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

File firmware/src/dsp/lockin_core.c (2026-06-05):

#include "zephyr_compat.h"
#include "lockin_core.h"

#include <string.h>

/*
 * Zephyr 2.7.1 in PlatformIO/Teensy can fail during the pre-link stage when
 * libm is pulled in. Keep this firmware self-contained: no sinf/cosf/sqrtf/
 * atan2f/fabsf symbols are required from libm. Accuracy is sufficient for a
 * first hardware bring-up; later this can be replaced by a LUT or CMSIS-DSP.
 */
static float lk_absf(float x)
{
    return (x < 0.0f) ? -x : x;
}

static float lk_wrap_pi(float x)
{
    const float two_pi = 2.0f * LOCKIN_PI;
    while (x > LOCKIN_PI) {
        x -= two_pi;
    }
    while (x < -LOCKIN_PI) {
        x += two_pi;
    }
    return x;
}

static float lk_sinf(float x)
{
    x = lk_wrap_pi(x);
    float x2 = x * x;
    /* 7th-order odd polynomial around 0 after wrapping to [-pi, pi]. */
    return x * (1.0f - (x2 / 6.0f) + ((x2 * x2) / 120.0f) - ((x2 * x2 * x2) / 5040.0f));
}

static float lk_cosf(float x)
{
    return lk_sinf(x + (0.5f * LOCKIN_PI));
}

static float lk_sqrtf(float x)
{
    if (x <= 0.0f) {
        return 0.0f;
    }
    float g = (x >= 1.0f) ? x : 1.0f;
    for (int i = 0; i < 8; ++i) {
        g = 0.5f * (g + (x / g));
    }
    return g;
}

static float lk_atan2f(float y, float x)
{
    if (x == 0.0f) {
        if (y > 0.0f) { return 0.5f * LOCKIN_PI; }
        if (y < 0.0f) { return -0.5f * LOCKIN_PI; }
        return 0.0f;
    }

    float abs_y = lk_absf(y) + 1.0e-12f;
    float angle;

    if (x >= 0.0f) {
        float r = (x - abs_y) / (x + abs_y);
        angle = (0.25f * LOCKIN_PI) - (0.25f * LOCKIN_PI * r);
    } else {
        float r = (x + abs_y) / (abs_y - x);
        angle = (0.75f * LOCKIN_PI) - (0.25f * LOCKIN_PI * r);
    }

    return (y < 0.0f) ? -angle : angle;
}


static lockin_config_t cfg;

static float x_in_f1[LOCKIN_MAX_HARMONICS];
static float x_in_f2[LOCKIN_MAX_HARMONICS];
static float y_qu_f1[LOCKIN_MAX_HARMONICS];
static float y_qu_f2[LOCKIN_MAX_HARMONICS];
static float x_mean[LOCKIN_MAX_HARMONICS];
static float y_mean[LOCKIN_MAX_HARMONICS];
static float x_var[LOCKIN_MAX_HARMONICS];
static float y_var[LOCKIN_MAX_HARMONICS];
static uint16_t sync_buffer[LOCKIN_SYNC_BUFFER_LEN];

static uint32_t sample_index;
static uint32_t time_to_sample;
static uint32_t newest_index;
static uint32_t oldest_index;
static uint32_t last_sample_us;
static uint32_t last_loop_us;
static float clip_value;
static float unlock_value;
static float alpha;
static float alpha_min;

static void recalc_internal_timing(void)
{
    if (cfg.signal_hz < 0.1f) {
        cfg.signal_hz = 0.1f;
    }
    if (cfg.sample_hz < 1.0f) {
        cfg.sample_hz = 1.0f;
    }

    cfg.samples_per_period = (uint32_t)(cfg.sample_hz / cfg.signal_hz);
    if (cfg.samples_per_period < 1u) {
        cfg.samples_per_period = 1u;
    }

    cfg.sample_dt_us = (uint32_t)(1000000.0f / cfg.sample_hz);
    if (cfg.sample_dt_us < 1u) {
        cfg.sample_dt_us = 1u;
    }

    cfg.sample_hz_true = 1000000.0f / (float)cfg.sample_dt_us;
    cfg.signal_hz_true = cfg.sample_hz_true / (float)cfg.samples_per_period;

    alpha = 1.0f / (cfg.sample_hz_true * cfg.time_constant_s);
    if (alpha < 0.0000001f) {
        alpha = 0.0000001f;
    }
    if (alpha > 1.0f) {
        alpha = 1.0f;
    }
    alpha_min = 1.0f - alpha;
}

static void reset_filters_unlocked(void)
{
    memset(x_in_f1, 0, sizeof(x_in_f1));
    memset(x_in_f2, 0, sizeof(x_in_f2));
    memset(y_qu_f1, 0, sizeof(y_qu_f1));
    memset(y_qu_f2, 0, sizeof(y_qu_f2));
    memset(x_mean, 0, sizeof(x_mean));
    memset(y_mean, 0, sizeof(y_mean));
    memset(x_var, 0, sizeof(x_var));
    memset(y_var, 0, sizeof(y_var));
    sample_index = 0u;
    time_to_sample = 0u;
    newest_index = 0u;
    oldest_index = 1u;
    last_sample_us = 0u;
    last_loop_us = 0u;
    clip_value = 0.0f;
    unlock_value = 0.0f;
}

void lockin_core_init(void)
{
    cfg.signal_hz = LOCKIN_DEFAULT_SIGNAL_HZ;
    cfg.sample_hz = LOCKIN_DEFAULT_SAMPLE_HZ;
    cfg.time_constant_s = LOCKIN_DEFAULT_TAU_S;
    cfg.phase_offset_rad = 0.0f;
    cfg.output_scale = LOCKIN_DEFAULT_OUTPUT_SCALE;
    cfg.calibration_factor = LOCKIN_INPUT_CAL;
    cfg.gain = LOCKIN_DEFAULT_GAIN;
    cfg.first_harmonic = 2u;
    cfg.last_harmonic = cfg.first_harmonic + LOCKIN_HARMONIC_COUNT - 1u;
    cfg.undersampling = 1u;
    cfg.oversampling = 1u;
    cfg.sync_filter_enabled = false;
    cfg.external_reference_enabled = false;
    recalc_internal_timing();
    reset_filters_unlocked();
    memset(sync_buffer, 0, sizeof(sync_buffer));
}

void lockin_core_reset_state(void)
{
    unsigned int key = irq_lock();
    reset_filters_unlocked();
    irq_unlock(key);
}

void lockin_core_clear_sync_buffer(void)
{
    unsigned int key = irq_lock();
    memset(sync_buffer, 0, sizeof(sync_buffer));
    newest_index = 0u;
    oldest_index = 1u;
    irq_unlock(key);
}

void lockin_core_get_config(lockin_config_t *out)
{
    unsigned int key = irq_lock();
    *out = cfg;
    irq_unlock(key);
}

void lockin_core_set_config(const lockin_config_t *new_cfg)
{
    unsigned int key = irq_lock();
    cfg = *new_cfg;
    recalc_internal_timing();
    reset_filters_unlocked();
    irq_unlock(key);
}

void lockin_core_set_gain(uint32_t gain)
{
    if (!(gain == 0u || gain == 1u || gain == 2u || gain == 4u || gain == 8u ||
          gain == 16u || gain == 32u || gain == 64u)) {
        return;
    }

    unsigned int key = irq_lock();
    cfg.gain = gain;
    cfg.calibration_factor = (gain == 0u) ? LOCKIN_INPUT_CAL : (LOCKIN_INPUT_CAL / (float)gain);
    irq_unlock(key);
}

void lockin_core_set_time_constant(float tau_s)
{
    if (tau_s <= 0.0001f) {
        tau_s = 0.0001f;
    }
    unsigned int key = irq_lock();
    cfg.time_constant_s = tau_s;
    recalc_internal_timing();
    irq_unlock(key);
}

void lockin_core_set_output_scale(float scale)
{
    if (scale < 0.0f) {
        scale = 0.0f;
    }
    unsigned int key = irq_lock();
    cfg.output_scale = scale;
    irq_unlock(key);
}

void lockin_core_set_first_harmonic(uint32_t first_harmonic)
{
    if (first_harmonic < 2u) {
        first_harmonic = 2u;
    }
    if ((first_harmonic + LOCKIN_HARMONIC_COUNT - 1u) > LOCKIN_MAX_HARMONICS) {
        first_harmonic = LOCKIN_MAX_HARMONICS - LOCKIN_HARMONIC_COUNT + 1u;
    }
    unsigned int key = irq_lock();
    cfg.first_harmonic = first_harmonic;
    cfg.last_harmonic = first_harmonic + LOCKIN_HARMONIC_COUNT - 1u;
    reset_filters_unlocked();
    irq_unlock(key);
}

void lockin_core_set_frequency(float signal_hz)
{
    if (signal_hz <= 0.1f) {
        signal_hz = 0.1f;
    }
    unsigned int key = irq_lock();
    cfg.signal_hz = signal_hz;
    cfg.external_reference_enabled = false;
    cfg.sample_hz = cfg.sync_filter_enabled ? LOCKIN_SYNC_SAMPLE_HZ : LOCKIN_DEFAULT_SAMPLE_HZ;
    cfg.undersampling = 1u;
    cfg.oversampling = 1u;
    recalc_internal_timing();
    reset_filters_unlocked();
    irq_unlock(key);
}
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
